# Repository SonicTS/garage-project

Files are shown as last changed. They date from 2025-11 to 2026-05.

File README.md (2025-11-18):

# blaulicht-garage-proxy (MQTT)

A DIY setup that routes the HTTPS traffic of one Android app ("Blaulicht") through a self-hosted mitmproxy. When a specific flow pattern is detected, the mitmproxy addon publishes an MQTT command to a local Mosquitto broker (TLS + auth). An ESP8266 subscribed to that topic pulses a relay to open the garage.

This repo includes: Android per-app VPN client, a mitmproxy addon with MQTT publishing, ESP8266 RTOS-based firmware with MQTT over TLS, and infrastructure templates (systemd, firewall, MQTT broker hardening). Intended for experimentation and learning.

## Data flow (MQTT)

```
[Blaulicht app]
      |
      v
Android per-app VPN (VpnService + tun2socks) → SOCKS5 → mitmproxy --(MQTT/TLS publish)--> Mosquitto → ESP8266 → relay
      ^                                 TLS intercept (trusted CA)                 ^ TLS + auth            (garage door)
```

## Components

- Android per-app VPN client
  - VpnService-based app that forwards only the target app’s traffic via a SOCKS5 proxy (mitmproxy) using a tun2socks AAR.
- mitmproxy addon
  - Detects the flow trigger and publishes `open` to `garage/cmd` over TLS to Mosquitto on 8883.
  - Configurable via environment variables (`MQTT_HOST`, `MQTT_USER/PASS`, `TRIGGER_*`). See `infra/systemd/mitmproxy.service`.
- Mosquitto broker
  - TLS 1.2+, per-user passwords in `/etc/mosquitto/passwd`, and minimal permissions. See `docs/setup-mqtt-broker.md`.
- ESP8266 firmware
  - Connects to Wi‑Fi and MQTT over TLS, subscribes to `garage/cmd`, and publishes `garage/status`. Embed the CA in `lib/mqtt/src/mqtt.c`.

## Quickstart

1) Server (Ubuntu)
- Install Mosquitto and set up TLS + users: `docs/setup-mqtt-broker.md`.
- Deploy mitmproxy addon and set MQTT env: `docs/setup-server-ubuntu.md`.

2) Android
- Build and install the per-app VPN client (Android Studio). Point it to the server’s SOCKS5 port. Install the mitmproxy CA on the device.

3) ESP8266
- Open `esp8266/Garage-Controller` in PlatformIO. Set Wi‑Fi + MQTT config (including CA). Build and flash.

Security note: Use strong per-client credentials. Keep the broker LAN-only or restricted. Self-signed CA is fine for local deployments; keep the private key secure.

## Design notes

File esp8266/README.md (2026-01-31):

# Garage Controller (ESP8266 RTOS)

Wi-Fi–enabled garage controller running on an ESP8266 (ESP-12F) using the
ESP8266 RTOS SDK and PlatformIO.

Main features (planned / in progress):

- STA + AP fallback Wi-Fi manager
- HTTP service interface for configuration
- Persistent configuration storage (Wi-Fi, MQTT, logic)
- Garage control logic (relays, sensors, alarms)
- MQTT integration for remote control / monitoring

## Project layout

- `src/`
  - `main.c` – SDK entrypoint (`user_init` + RF cal) that just calls `app_start()`.
- `lib/`
  - `app/` – top-level orchestration: starts Wi-Fi, HTTP, garage logic, etc.
  - `wifi_manager/` – STA/AP state machine, retries, IP tracking.
  - `service_interface/` – HTTP/REST-style configuration API.
  - `config_store/` – configuration structs + persistence (flash).
  - `garage_control/` – garage-door specific logic (GPIO, sensors, alarms).
  - `mqtt/` – MQTT client wrapper and integration.

## Build / flash

```bash
# Build
pio run

# Upload firmware
pio run -t upload

# Serial monitor
pio device monitor
```

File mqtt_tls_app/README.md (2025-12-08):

# mqtt_tls_app

A new Flutter project.

## Getting Started

This project is a starting point for a Flutter application.

A few resources to get you started if this is your first Flutter project:

- [Lab: Write your first Flutter app](https://docs.flutter.dev/get-started/codelab)
- [Cookbook: Useful Flutter samples](https://docs.flutter.dev/cookbook)

For help getting started with Flutter development, view the
[online documentation](https://docs.flutter.dev/), which offers tutorials,
samples, guidance on mobile development, and a full API reference.

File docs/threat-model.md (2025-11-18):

# Threat Model (MQTT)

Plain-language overview of what we’re defending against and what is out of scope for this hobby setup.

## Goals / What We Try To Protect Against

- Random Internet scanners or bots hitting open ports.
- Opportunistic attackers targeting open MQTT (8883) or SOCKS5 ports.
- Accidental or unauthorized triggering of the garage door via MQTT command injection.
- Simple replay scenarios via repeated publishes if cooldowns are bypassed.

## Non-Goals / Out of Scope

- Highly resourced or motivated attackers targeting the system directly.
- Physical compromise of the ESP8266, relay, or wiring (someone steals the board).
- Advanced MITM attacks against TLS (assumes correct certificate management and no device tampering).
- Protecting against someone who already has root on the server.

## Assets

- Ability to open the garage door.
- MQTT credentials stored in `/etc/mosquitto/passwd`.
- Integrity of command flow between mitmproxy addon and mosquitto broker.

## Attack Surfaces

- MQTT over TLS on 8883 (should be LAN-only or source-restricted).
- SOCKS5 port for the phone (restricted firewall rules recommended).

## Mitigations

- MQTT broker is LAN-only or source-restricted; TLS 1.2+ with strong per-client passwords.
- Separate Unix users `mitmproxy` and `mosq` to reduce lateral impact.
- Firewall: restrict SOCKS5 and 8883; allow SSH.
- TLS on MQTT; self-signed CA with ESP8266 embedding; server key permissions locked down.
- mitmproxy cooldown on publishes to reduce accidental repeats.

## Residual Risks / Trade-offs

- Passwords in mosquitto passwd; protect file mode; consider per-device accounts.
- ESP8266 TLS validation relies on embedded CA; keep CA private key offline.
- No rate limiting on MQTT by default—consider connection limits and auth lockouts.

## Future Hardening Ideas

- Consider mTLS or per-device topics.
- Implement limited command history or deduplication on firmware side.
- Add systemd sandboxing directives for mitmproxy and mosquitto.
- Monitor logs for unusual connection attempts or repeated publishes.

## Summary

Security posture: “Reasonable for a hobby project.” It reduces exposure, uses TLS and per-client credentials, and isolates components. It is not designed for high-assurance environments—treat it as a learning platform.

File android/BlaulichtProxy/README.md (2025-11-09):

# BlaulichtProxy (Android)

This folder holds the Android Studio project for the per-app VPN client.

- VpnService-based app that uses a tun2socks AAR to forward only the Blaulicht app’s traffic to a SOCKS5 proxy (mitmproxy).

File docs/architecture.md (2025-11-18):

# Architecture (MQTT)

This document describes the updated MQTT-based design. mitmproxy detects the app’s flow pattern and publishes an MQTT command to a local Mosquitto broker (TLS + auth). The ESP8266 subscribes to that command topic and publishes status back.

## High-Level Diagram

```
(Android Phone)
+-------------------+      SOCKS5        +------------+       MQTT (TLS)       +--------------------+      Relay
| Blaulicht App     | ---> per-app VPN --|  mitmproxy |--pub--> garage/cmd ---> |   Mosquitto Broker | --->  ESP8266
+-------------------+      (tun2socks)   +------------+<-sub-- garage/status <--+ (localhost:8883)   |   (subscribe cmd,
   | HTTPS Req.             | TLS intercept (CA trusted)                        ^ auth+TLS          |    publish status)
   v                        | inspects flows                                    |                   v
 Normal app logic               | addon publishes command                           |               Garage Door
```

## Step-by-Step Data Flow

1. The Blaulicht app sends HTTPS requests as part of its normal operation.
2. The Android per-app VPN (VpnService + tun2socks) forwards ONLY that app’s TCP streams to mitmproxy (SOCKS5).
3. mitmproxy (trusted CA on the phone) sees HTTP metadata and matches a configured trigger.
4. The mitmproxy addon publishes `GARAGE_CMD_PAYLOAD` (default `open`) to topic `garage/cmd` over TLS to the local Mosquitto broker on 8883.
5. The ESP8266 (RTOS SDK + mbedTLS) is connected to the same broker, subscribes to `garage/cmd`, and when it receives `open`, pulses the relay.
6. The ESP8266 publishes `garage/status` updates (e.g., `idle`, `opening`, `opened`, `closed`) that mitmproxy or dashboards can consume.

## Responsibilities

- mitmproxy: Detects pattern and publishes MQTT command. No long-term state.
- Mosquitto: Authenticates clients, terminates TLS, routes topics.
- ESP8266: MQTT client; subscribes to command topic and publishes status.

## Trust Boundaries

- Broker listens on `localhost:8883` or LAN-restricted 8883/TCP with TLS 1.2+.
- Strong username/password per client; broker runs as locked-down system user.
- Self-signed private CA recommended for local deployments; embed CA in firmware.

## Open Items / TODOs

- Fine-tune mitmproxy trigger conditions (SNI, CONNECT host:port, URL substring).
- Debounce commands (mitmproxy has cooldown; firmware may also enforce cooldown).
- Optional: mTLS or per-device topics like `garage/door1/cmd`.

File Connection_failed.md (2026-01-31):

Flash map=4, rf_cal_sector=1019
Reset reason: 6, exccause=0, epc1=0x00000000
app: Starting app...
app: event queue created
config_store: using flash sector 1018 for config
config_store: loaded config from flash
app: config store initialized
app: config loaded
sleep disable
app: wifi manager initialized
service_interface: starting socket HTTP server on 80 (heap=37280)
service_interface: listening socket=0
app: service interface initialized
app: mqtt client initialized
GPIO init result: 0
garage_control: initialized (task=3fff9760)
app: garage control initialized
mode : sta(c8:c9:a3:38:5b:d3)
add if0
wifi_manager: starting scan for SSID "Barrique"
mqtt: waiting for WIFI_UP...
service_interface: http server task running
scandone
wifi_manager: === Scan Results - All WiFi Networks ===
  SSID: Thomas_Hotspot                   | BSSID: 4a:19:95:d2:f3:e6 | Ch:  6 | RSSI: -34 dBm | Auth: 3
  SSID: Barrique                         | BSSID: 1c:ed:6f:f5:57:1c | Ch: 11 | RSSI: -59 dBm | Auth: 4
wifi_manager: === End of Scan Results ===
wifi_manager: scan done, 1 candidate(s) for SSID "Barrique"
  cand 1: BSSID 1c:ed:6f:f5:57:1c ch=11 rssi=-59
wifi_manager: using BSSID 1c:ed:6f:f5:57:1c, channel 11
wifi_manager: STA connecting to "Barrique"
scandone
state: 0 -> 2 (b0)
state: 2 -> 3 (0)
state: 3 -> 5 (10)
add 0
aid 5
pm open phy_2,type:0 0 0
cnt 
state: 5 -> 2 (2a0)
rm 0
pm close 7 0 0/4042667
wifi_manager: starting scan for SSID "Barrique"
scandone
wifi_manager: === Scan Results - All WiFi Networks ===
  SSID: Barrique_VAP                     | BSSID: 80:3f:5d:83:fd:1e | Ch: 11 | RSSI: -85 dBm | Auth: 3
  SSID: Barrique                         | BSSID: 1c:ed:6f:f5:57:1c | Ch: 11 | RSSI: -59 dBm | Auth: 4
  SSID: Thomas_Hotspot                   | BSSID: 4a:19:95:d2:f3:e6 | Ch:  6 | RSSI: -37 dBm | Auth: 3
wifi_manager: === End of Scan Results ===
wifi_manager: scan done, 1 candidate(s) for SSID "Barrique"
  cand 1: BSSID 1c:ed:6f:f5:57:1c ch=11 rssi=-59
wifi_manager: DHCP timeout, switching candidate
state: 2 -> 0 (0)
wifi_manager: candidates exhausted, trying SSID-only connect (dhcp-timeout
wifi_manager: no BSSID lock, connecting by SSID only
wifi_manager: STA connecting to "Barrique"
wifi_manager: starting scan for SSID "Barrique"
scandone
scandone
wifi_manager: === Scan Results - All WiFi Networks ===
  SSID: Thomas_Hotspot                   | BSSID: 4a:19:95:d2:f3:e6 | Ch:  6 | RSSI: -45 dBm | Auth: 3
  SSID: Barrique                         | BSSID: 1c:ed:6f:f5:57:1c | Ch: 11 | RSSI: -59 dBm | Auth: 4
  SSID: Barrique_VAP                     | BSSID: 80:3f:5d:83:fd:1e | Ch: 11 | RSSI: -91 dBm | Auth: 3
wifi_manager: === End of Scan Results ===
wifi_manager: scan done, 1 candidate(s) for SSID "Barrique"
  cand 1: BSSID 1c:ed:6f:f5:57:1c ch=11 rssi=-59
reconnect
scandone
state: 0 -> 2 (b0)
state: 2 -> 3 (0)
state: 3 -> 5 (10)
add 0
aid 5
pm open phy_2,type:0 0 0
cnt 
state: 5 -> 2 (2a0)
rm 0
pm close 7 0 0/4044221
wifi_manager: starting scan for SSID "Barrique"
scandone
wifi_manager: === Scan Results - All WiFi Networks ===
  SSID: Barrique                         | BSSID: 1c:ed:6f:f5:57:1c | Ch: 11 | RSSI: -59 dBm | Auth: 4
wifi_manager: === End of Scan Results ===
wifi_manager: scan done, 1 candidate(s) for SSID "Barrique"
  cand 1: BSSID 1c:ed:6f:f5:57:1c ch=11 rssi=-59
wifi_manager: DHCP timeout, switching candidate
state: 2 -> 0 (0)
wifi_manager: candidates exhausted, trying SSID-only connect (dhcp-timeout
wifi_manager: no BSSID lock, connecting by SSID only
wifi_manager: STA connecting to "Barrique"
wifi_manager: starting scan for SSID "Barrique"
scandone
scandone
wifi_manager: === Scan Results - All WiFi Networks ===
  SSID: Barrique                         | BSSID: 1c:ed:6f:f5:57:1c | Ch: 11 | RSSI: -57 dBm | Auth: 4
  SSID: Thomas_Hotspot                   | BSSID: 4a:19:95:d2:f3:e6 | Ch:  6 | RSSI: -36 dBm | Auth: 3
wifi_manager: === End of Scan Results ===
wifi_manager: scan done, 1 candidate(s) for SSID "Barrique"
  cand 1: BSSID 1c:ed:6f:f5:57:1c ch=11 rssi=-57
reconnect
scandone
state: 0 -> 2 (b0)
state: 2 -> 3 (0)
state: 3 -> 5 (10)
add 0
aid 5
pm open phy_2,type:0 0 0
cnt 
state: 5 -> 2 (2a0)
rm 0
pm close 7 0 0/4043693
wifi_manager: starting scan for SSID "Barrique"
scandone
wifi_manager: === Scan Results - All WiFi Networks ===
  SSID: Barrique_VAP                     | BSSID: 80:3f:5d:83:fd:1e | Ch: 11 | RSSI: -83 dBm | Auth: 3
  SSID: Thomas_Hotspot                   | BSSID: 4a:19:95:d2:f3:e6 | Ch:  6 | RSSI: -37 dBm | Auth: 3
wifi_manager: === End of Scan Results ===
wifi_manager: scan done, SSID "Barrique" not found -> AP fallback
wifi_manager: switching to AP mode
state: 2 -> 0 (0)
del if0
usl
sul 0 0
mode : softAP(ca:c9:a3:38:5b:d3)
dhcp server start:(ip:192.168.4.1,mask:255.255.255.0,gw:192.168.4.1)
add if1
bcn 100
bcn 0
del if1
usl
sul 0 0
dhcp server start:(ip:192.168.4.1,mask:255.255.255.0,gw:192.168.4.1)
add if1
bcn 100
wifi_manager: SoftAP active: SSID=ESP8266-Setup, password=esp8266pw

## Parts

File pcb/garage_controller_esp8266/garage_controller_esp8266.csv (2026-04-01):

Id | Designator | Footprint | Quantity | Designation | Supplier and ref
1 | R4 | R_0805_2012Metric_Pad1.20x1.40mm_HandSolder | 1 | 0
2 | U1 | Wemos D1 mini connectort | 1 | Wemos D1 mini connector
3 | D1 | LED_0805_2012Metric_Pad1.15x1.40mm_HandSolder | 1 | LED
4 | C1 | C_0805_2012Metric_Pad1.18x1.45mm_HandSolder | 1 | 10uF
5 | Q1,Q3,Q2 | SOT-23 | 3 | 2N7002
6 | R1,R3,R2 | R_0805_2012Metric_Pad1.20x1.40mm_HandSolder | 3 | 1k
7 | C7,C4,C2,C6,C5 | C_0805_2012Metric_Pad1.18x1.45mm_HandSolder | 5 | 100nF
8 | R19,R17,R20,R11,R15,R14 | R_0805_2012Metric_Pad1.20x1.40mm_HandSolder | 6 | 330R
9 | R6,R10,R12,R8,R9,R7 | R_0805_2012Metric_Pad1.20x1.40mm_HandSolder | 6 | 10k
10 | D2 | D_SOD-123 | 1 | 1N5819
11 | R13,R16,R18 | R_0805_2012Metric_Pad1.20x1.40mm_HandSolder | 3 | 100k
12 | U2 | SOIC-28W_7.5x17.9mm_P1.27mm | 1 | MCP23017_SO
13 | J2 | PinSocket_1x03_P2.54mm_Vertical | 1 | Conn_01x03_Socket
14 | R5 | R_1206_3216Metric_Pad1.30x1.75mm_HandSolder | 1 | 3k3
15 | D3,D4 | SOT-323_SC-70 | 2 | SP0502BAJT
16 | J1 | PinSocket_1x09_P2.54mm_Vertical | 1 | Connections
17 | C3 | CP_Elec_10x12.5 | 1 | 220uF

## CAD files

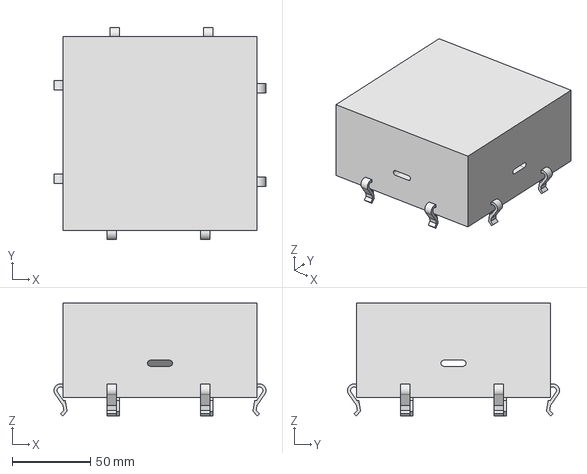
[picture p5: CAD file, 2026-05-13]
pcb/Garage-Box-Project/Top_part_improved.stp
135.7 x 135.7 x 72.2 mm

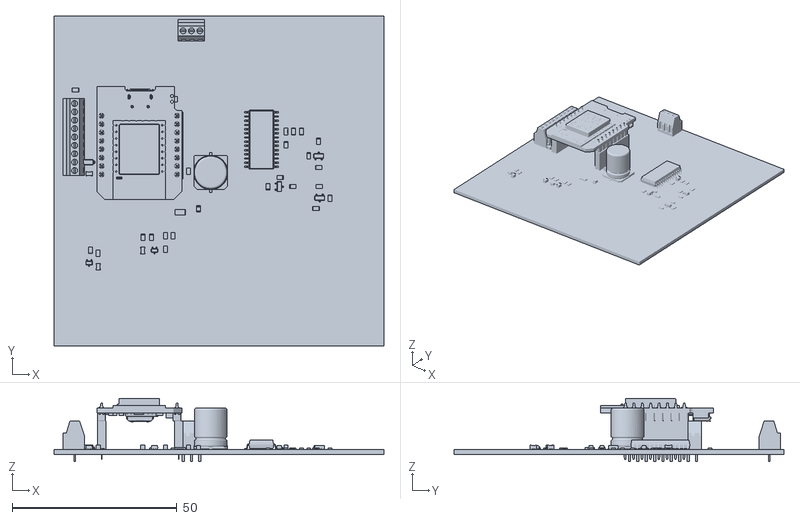
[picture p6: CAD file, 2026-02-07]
pcb/garage_controller_esp8266/Platine.stl
100.0 x 100.0 x 19.2

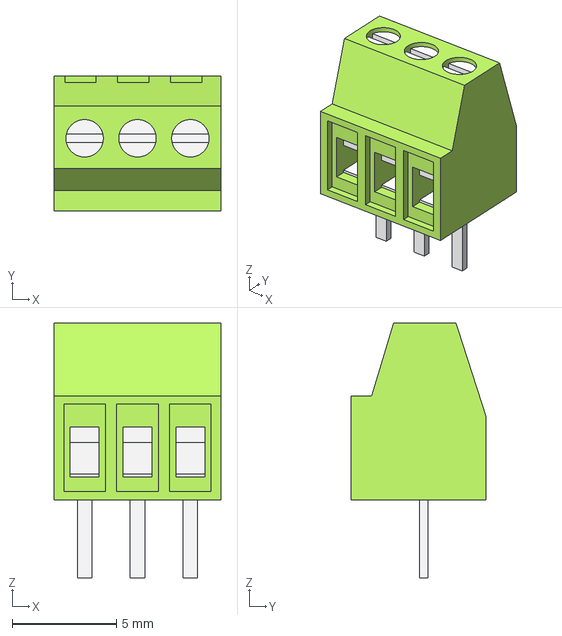
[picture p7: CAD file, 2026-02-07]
pcb/KF128-2.54-3P.step
8.02 x 6.50 x 12.3 mm
Housing
PlasticBody

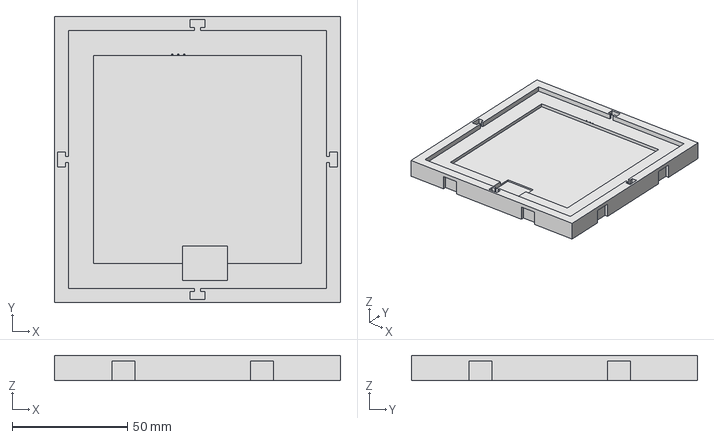
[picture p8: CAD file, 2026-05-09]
pcb/Garage-Box-Project/Bottom_part_improved.stp
124.0 x 124.0 x 11.0 mm

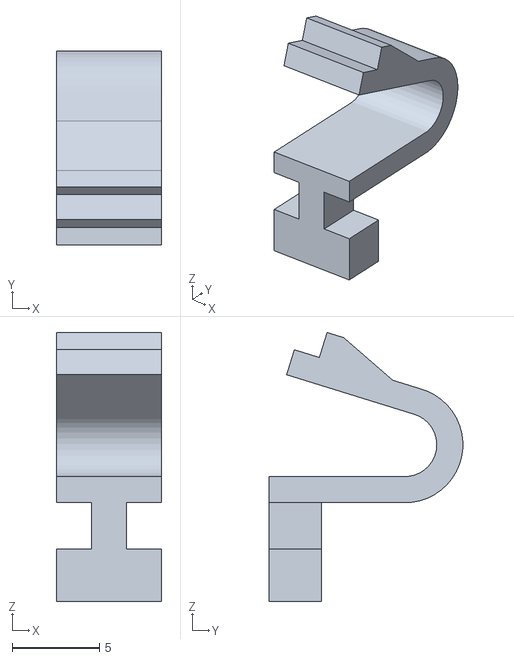
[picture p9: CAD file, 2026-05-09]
pcb/Garage-Box-Project/Clipper_different.stl
6.00 x 11.1 x 15.4

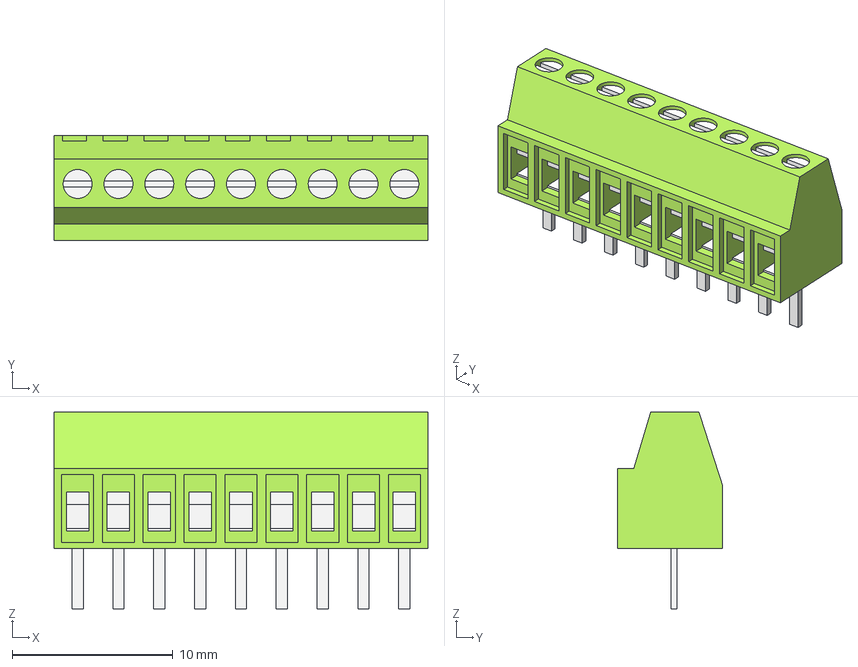
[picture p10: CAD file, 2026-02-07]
pcb/KF128-2.54-9P.step
23.3 x 6.50 x 12.3 mm
Housing
PlasticBody

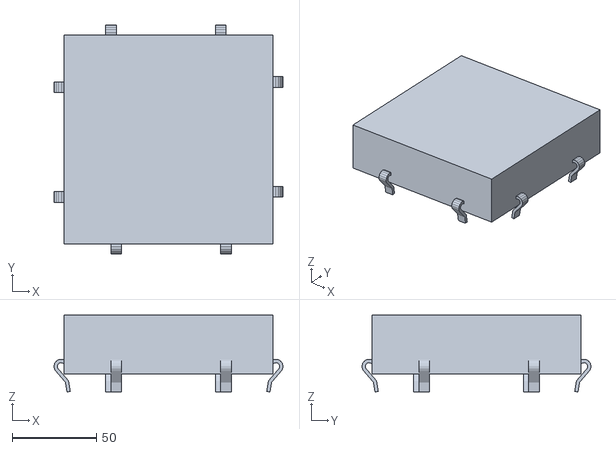
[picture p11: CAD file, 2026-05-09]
pcb/Garage-Box-Project/Top_part_clip.stl
135.7 x 135.7 x 45.6

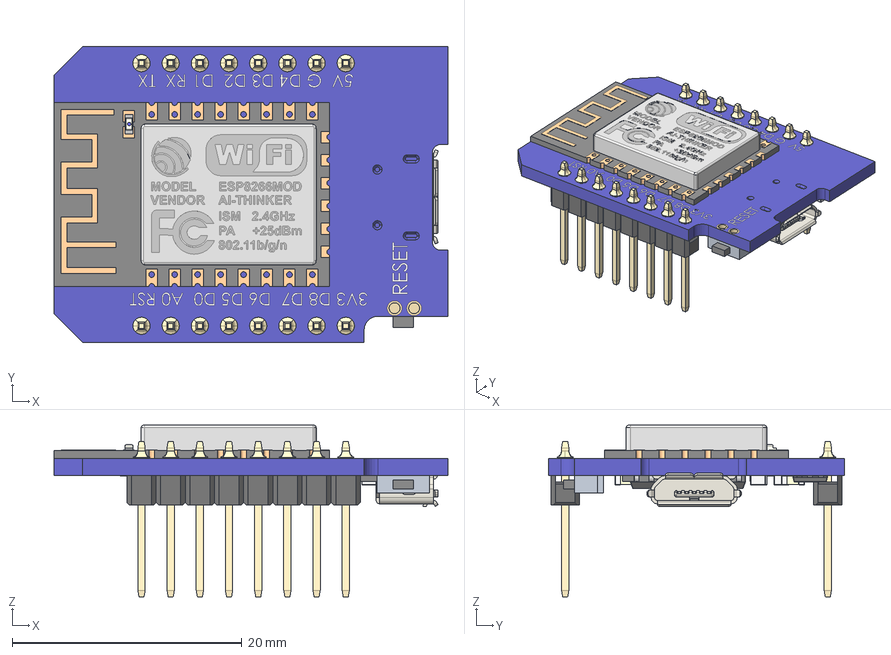
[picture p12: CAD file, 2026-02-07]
pcb/wemos-mini-d1.stp
34.3 x 25.8 x 14.9 mm
PRODUCT_146_ASM_2
PRODUCT_260_3
PRODUCT_323_ASM_2
RES_0805_1 x 12
CAP_0805_1 x 7
SOT23_1_1 x 2
SOT23_2_1 x 2
SOT23_3_1 x 2
SOT23_001_1 x 2
SOT23-5_1
SOT23-5_001_1_1
SOT23-5_001_2_1
SOT23-5_001_3_1
SOT23-5_001_4_1
SOT23-5_001_5_1
SOD-323_1
SOIC-16_150MIL_1
SOIC-16_150MIL_001_1_1
SOIC-16_150MIL_001_2_1
SOIC-16_150MIL_001_3_1
SOIC-16_150MIL_001_4_1
SOIC-16_150MIL_001_5_1
SOIC-16_150MIL_001_6_1
SOIC-16_150MIL_001_7_1
SOIC-16_150MIL_001_8_1
SOIC-16_150MIL_001_9_1
SOIC-16_150MIL_001_10_1
SOIC-16_150MIL_001_11_1
SOIC-16_150MIL_001_12_1
SOIC-16_150MIL_001_13_1
SOIC-16_150MIL_001_14_1
SOIC-16_150MIL_001_15_1
SOIC-16_150MIL_001_16_1
COMPONENTS_2_11__2
_PUSH_BUTTON_-_IMPORTIERT1__2
_USB_SOCKET_-_IMPORTIERT1__2
PCB_2
PIN x 16

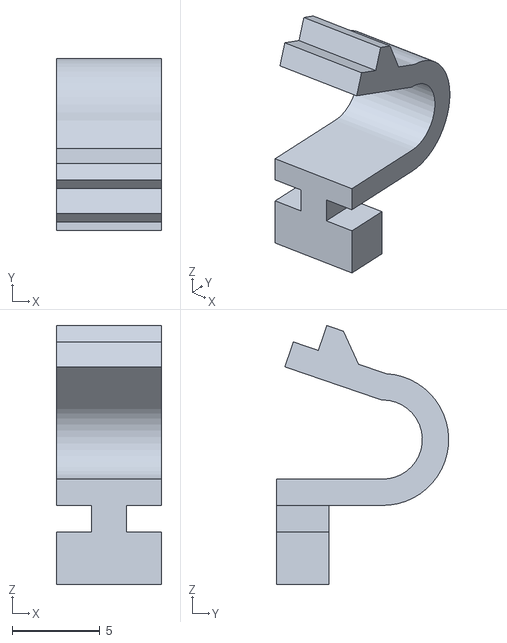
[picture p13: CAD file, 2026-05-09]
pcb/Garage-Box-Project/Clipper_1_5_thickness.stl
6.00 x 9.81 x 14.7

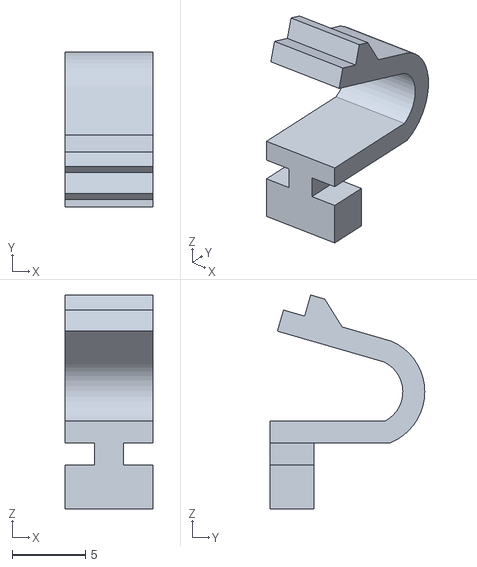
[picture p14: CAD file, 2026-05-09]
pcb/Garage-Box-Project/Clipper_1_5_thickness_smaller.stl
6.00 x 10.6 x 14.6

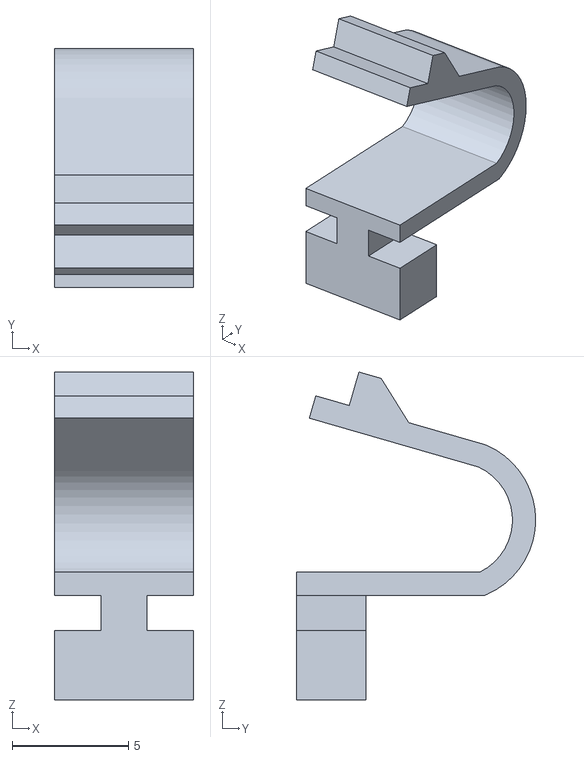
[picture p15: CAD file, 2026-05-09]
pcb/Garage-Box-Project/Clipper_1_0_thickness_smaller.stl
6.00 x 10.3 x 14.1

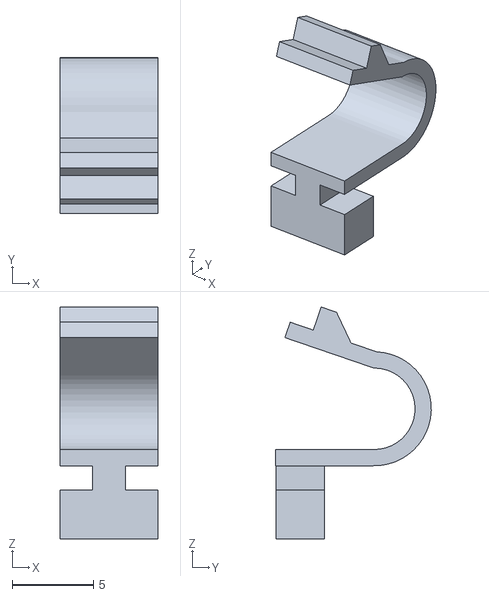
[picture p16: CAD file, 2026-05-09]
pcb/Garage-Box-Project/Clipper_1_0_thickness.stl
6.00 x 9.56 x 14.3

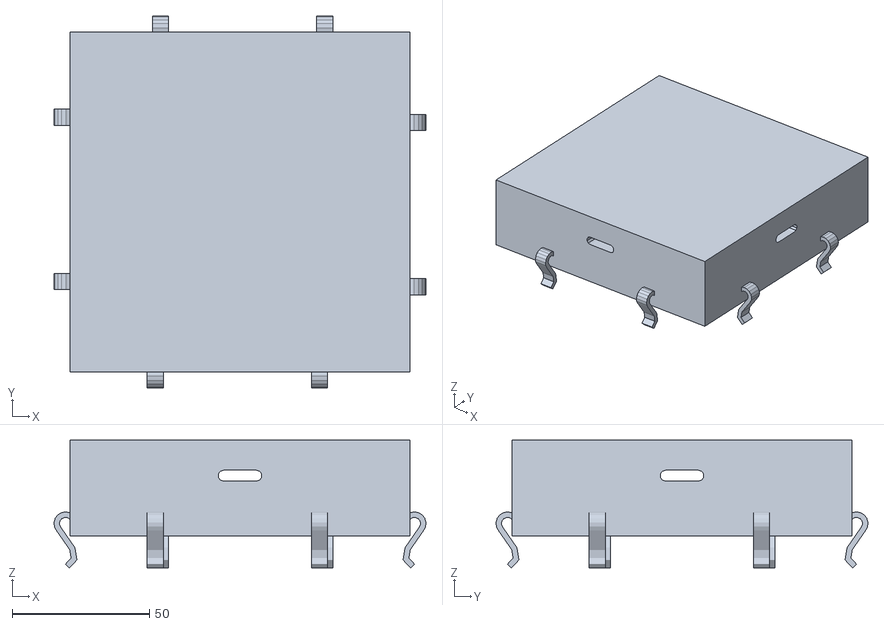
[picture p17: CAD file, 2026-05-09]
pcb/Garage-Box-Project/Top_part.stl
135.7 x 135.7 x 46.7

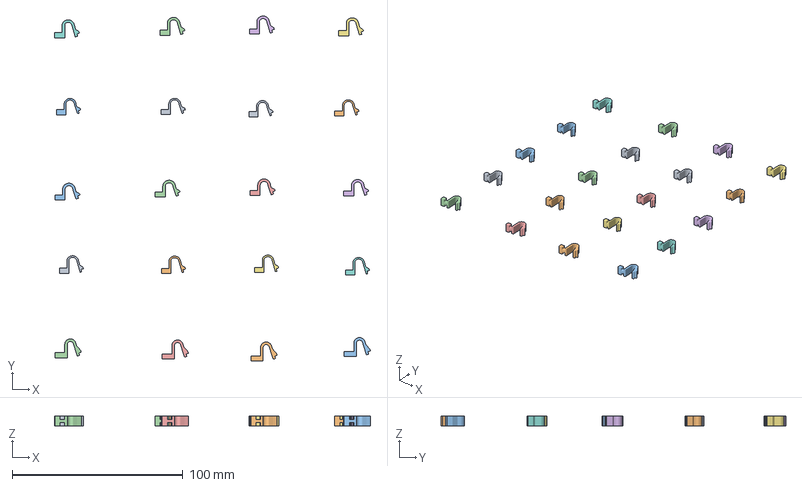
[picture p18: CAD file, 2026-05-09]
pcb/Garage-Box-Project/Clippers.3mf
185.0 x 201.9 x 6.00 mm
Clipper_1_0_thickness.stl x 4
Clipper_1_0_thickness_smaller.stl x 4
Clipper_1_5_thickness.stl x 4
Clipper_1_5_thickness_smaller.stl x 4
Clipper_different.stl x 4

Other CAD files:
pcb/garage_controller_esp8266.step
pcb/Garage-Box-Project/Clipper.stl
pcb/Garage-Box-Project/Clipper_thinner.stl
pcb/Garage-Box-Project/Clipper_wider.stl
pcb/Garage-Box-Project/Assembly_GaragenBox.iam
pcb/Garage-Box-Project/BoxPrintTryout.stl
pcb/Garage-Box-Project/Box_derived.ipt
pcb/Garage-Box-Project/Box_derived.stl
pcb/Garage-Box-Project/Box_with_PCBRefernce.ipt
pcb/Garage-Box-Project/Clipper.ipt
pcb/Garage-Box-Project/Clipper_aligned.ipt
pcb/Garage-Box-Project/OldVersions/Assembly_GaragenBox.0009.iam
pcb/Garage-Box-Project/OldVersions/Box_derived.0006.ipt
pcb/Garage-Box-Project/OldVersions/Box_with_PCBRefernce.0018.ipt
pcb/Garage-Box-Project/OldVersions/Clipper.0017.ipt
pcb/Garage-Box-Project/OldVersions/SolidBody_PCB_better.0003.ipt
pcb/Garage-Box-Project/OldVersions/Top_part.0015.ipt
pcb/Garage-Box-Project/OldVersions/Top_part_only.0001.ipt
pcb/Garage-Box-Project/Part1.stp
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

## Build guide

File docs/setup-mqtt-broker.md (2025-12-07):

# Secure MQTT Broker Setup on Ubuntu (Mosquitto + TLS + Auth)

This guide installs a secure Mosquitto broker with TLS, strong authentication, a dedicated system user, strict permissions, and firewall rules. It’s compatible with ESP8266 (RTOS SDK + mbedTLS) and standard MQTT clients.

## 1) Install Mosquitto Broker & Clients

```bash
sudo apt update
sudo apt install mosquitto mosquitto-clients
```

Verify the service:

```bash
sudo systemctl status mosquitto
```

## 2) Create a Dedicated Mosquitto User

Run Mosquitto as a locked-down system user (create user + group together):

```bash
sudo adduser --system --no-create-home --disabled-password --group mosq
```

## 3) Create Secure TLS Certificates (Self-signed CA)

Use the provided generator script (creates a private CA and a server cert with proper SANs and permissions). Edit the SAN config first, then run the generator:

```bash
sudo mkdir -p /etc/mosquitto/certs
# Copy the SAN config and edit placeholders (LAN IP, hostnames)
sudo cp ./infra/mosquitto/openssl-san.cnf /etc/mosquitto/certs/openssl-san.cnf
sudo nano /etc/mosquitto/certs/openssl-san.cnf

# Generate CA + server cert using the SAN config
sudo bash ./infra/mosquitto/gen-server-cert.sh --config /etc/mosquitto/certs/openssl-san.cnf
```

CA file for devices: `/etc/mosquitto/certs/ca.crt` (copy its PEM contents into your ESP firmware).

## 4) Create Mosquitto Password File (Client Authentication)

```bash
sudo mosquitto_passwd -c /etc/mosquitto/passwd espclient
# Prompted for password

# (Recommended) create a user for mitmproxy addon too:
sudo mosquitto_passwd /etc/mosquitto/passwd mitmclient

sudo chown mosq:mosq /etc/mosquitto/passwd
sudo chmod 600 /etc/mosquitto/passwd
```

Tip: For quick testing only, `mosquitto_sub` can skip hostname verification with `--insecure`, but the proper fix is issuing the server cert with a SAN that matches the host you connect to (e.g. `localhost` or your DNS name).

## 5) Configure Secure Listener (TLS + Auth)

Use the provided infra files

```bash
# Copy ready-to-use configs
sudo cp ./infra/mosquitto/secure.conf /etc/mosquitto/conf.d/secure.conf
sudo cp ./infra/mosquitto/acl /etc/mosquitto/acl

# Ensure mosquitto runs as custom user mosq with sane pre-start steps
sudo mkdir -p /etc/systemd/system/mosquitto.service.d
sudo cp ./infra/mosquitto/override.conf /etc/systemd/system/mosquitto.service.d/override.conf
sudo systemctl daemon-reload
```

Reload and check logs:

```bash
sudo systemctl restart mosquitto
sudo journalctl -u mosquitto -f
```

If you see errors like:

```
Error: Unable to open log file /var/log/mosquitto/mosquitto.log for writing.
Error: Unable to load server key file "/etc/mosquitto/certs/server.key". Check keyfile.
```

Fix them:

1. Ensure the runtime user matches file ownership. Using custom user `mosq` everywhere is recommended; all certs, key, CA, passwd and log directory must be owned by `mosq:mosq` with restrictive permissions on the private key.
  - To confirm custom user is applied:
    ```bash
    sudo systemctl edit mosquitto
    # In the editor ensure:
    [Service]
    User=mosq
    Group=mosq
    ```
    Then reload:
    ```bash
    sudo systemctl daemon-reload
    ```
  - Or revert the line in `secure.conf` to `user mosquitto` and adjust ownership:
    ```bash
    sudo chown mosquitto:mosquitto /etc/mosquitto/certs/server.key /etc/mosquitto/certs/server.crt /etc/mosquitto/certs/ca.crt
    sudo chown mosquitto:mosquitto /etc/mosquitto/passwd
    ```
2. Create log directory and file with correct ownership (only if using file logging):
  ```bash
  sudo mkdir -p /var/log/mosquitto
  sudo touch /var/log/mosquitto/mosquitto.log
  sudo chown mosq:mosq /var/log/mosquitto/mosquitto.log /var/log/mosquitto
  sudo chmod 640 /var/log/mosquitto/mosquitto.log
  # (Use mosquitto:mosquitto if you reverted user.)
  ```
3. Restart again:
  ```bash
  sudo systemctl restart mosquitto
  sudo journalctl -u mosquitto -f
  ```

Optional: Instead of a file log, you can remove any `log_dest file` directive and rely on syslog (`log_dest syslog`) to avoid managing permissions.

## 6a) Troubleshooting "Protocol error" on TLS connect

If `mosquitto_sub` reports `Error: Protocol error` on a TLS listener:

Likely causes:
- Wrong port (connecting TLS client to a plain listener or vice versa).
- Certificate/key unreadable by runtime user (results in the broker starting without TLS, or failing; verify service status).
- Client missing `--cafile` or using an incorrect CA (handshake aborts early).
- Corrupted or wrong format key/certificate (must be PEM, not DER).
- Mixed permissions (server.key not readable by the broker user).

Diagnostics:
```bash
sudo systemctl status mosquitto
sudo journalctl -u mosquitto | tail -n 30
openssl s_client -connect localhost:8883 -servername localhost -CAfile /etc/mosquitto/certs/ca.crt -quiet
mosquitto_sub -d -h localhost -p 8883 --cafile /etc/mosquitto/certs/ca.crt -u espclient -P 'YOURPASSWORD' -t test/topic
```

Check that `openssl s_client` ends with `Verify return code: 0 (ok)`.

Permissions sanity:
```bash
ls -l /etc/mosquitto/certs
ls -l /etc/mosquitto/passwd
```

Expected:
- `server.key` : `-rw------- mosq mosq`
- `server.crt` / `ca.crt` : `-rw-r--r-- mosq mosq`
- `passwd` : `-rw------- mosq mosq`

If the broker runs as default user instead, adjust ownership to `mosquitto:mosquitto` accordingly.

Regenerate a broken key/cert pair (if needed):
```bash
cd /etc/mosquitto/certs
sudo openssl genrsa -out server.key 2048
sudo openssl req -new -key server.key -out server.csr
sudo openssl x509 -req -in server.csr -CA ca.crt -CAkey ca.key -CAcreateserial -out server.crt -days 3650
sudo rm server.csr
sudo chown mosq:mosq server.key server.crt
sudo chmod 600 server.key
sudo chmod 644 server.crt
sudo systemctl restart mosquitto
```

## 6) Firewall (iptables)

```bash
# Allow TLS MQTT 8883 (any source)
sudo iptables -A INPUT -p tcp --dport 8883 -j ACCEPT

# Optional: restrict to LAN instead of anywhere
# sudo iptables -A INPUT -p tcp -s 192.168.0.0/16 --dport 8883 -j ACCEPT

# Persist rules across reboots (Debian/Ubuntu)
sudo apt install -y iptables-persistent
sudo netfilter-persistent save
```

Allow entire private networks (RFC1918) only:

```bash
# 10.0.0.0/8
sudo iptables -A INPUT -p tcp -s 10.0.0.0/8 --dport 8883 -j ACCEPT
# 172.16.0.0/12
sudo iptables -A INPUT -p tcp -s 172.16.0.0/12 --dport 8883 -j ACCEPT
# 192.168.0.0/16
sudo iptables -A INPUT -p tcp -s 192.168.0.0/16 --dport 8883 -j ACCEPT

# Remove any broad allow added earlier if present
# sudo iptables -D INPUT -p tcp --dport 8883 -j ACCEPT || true

sudo netfilter-persistent save
```

Tip (TLS SAN when you don’t have a domain or stable public IP):
- Include entries you actually use: `DNS:localhost`, `IP:127.0.0.1`, your LAN IP `IP:<LAN_IP>`.
- For outside access without a domain, either use a free DDNS (DuckDNS, No-IP, Dynu) and put `DNS:<your-ddns>` in SAN, or connect by your current public IP and include that `IP:<PUBLIC_IP>` in SAN (you’ll need to reissue the cert when it changes). For quick tests, clients like mosquitto_sub can use `--insecure` to skip hostname verification.

## 7) Test the Broker

Terminal A (subscribe):

```bash
mosquitto_sub -v \
  -h localhost \
  -p 8883 \
  --cafile /etc/mosquitto/certs/ca.crt \
  -u espclient \
  -P "12_espclient_34" \
  -t "garage/topic"
```

Terminal B (publish):

```bash
mosquitto_pub \
  -h localhost \
  -p 8883 \
  --cafile /etc/mosquitto/certs/ca.crt \
  -u espclient \
  -P "12_espclient_34" \
  -t "garage/cmd" \
  -m "OPEN"
```

Expected output in terminal A:

```
test/topic Hello MQTT!
```

## 11) Final Checklist

- User and ownership:
  - Runtime user `mosq` exists: `id mosq`
  - Certs and passwd owned by `mosq:mosq`: `ls -l /etc/mosquitto/certs /etc/mosquitto/passwd`
  - Permissions: `server.key` 600; `server.crt` and `ca.crt` 644; `passwd` 600
- TLS certificate:
  - SAN includes what you connect to: `localhost`, `<LAN_IP>`, and optionally `<YOUR_DDNS_OR_HOSTNAME>`
  - Verify: `openssl x509 -in /etc/mosquitto/certs/server.crt -noout -text | sed -n '/Subject Alternative Name/,+1p'`
  - Handshake: `openssl s_client -connect localhost:8883 -servername localhost -CAfile /etc/mosquitto/certs/ca.crt -quiet` should end with `Verify return code: 0 (ok)`
- Mosquitto config:
  - `per_listener_settings true` appears before any security lines
  - Listener 8883 has `cafile/certfile/keyfile/tls_version`
  - Security after listener: `user mosq`, `allow_anonymous false`, `password_file ...`, optional `acl_file`
- Auth:
  - Password set: `sudo mosquitto_passwd -b /etc/mosquitto/passwd espclient 'YOURPASSWORD'`
  - Optional ACL grants topics to `espclient`
- Firewall:
  - Open TCP 8883 via iptables (optionally restrict to LAN or RFC1918)

After any change:
```bash
sudo systemctl restart mosquitto
sudo journalctl -u mosquitto -f
```

## 8) ESP8266 Compatibility

Configure firmware with:
- host: broker IP (or hostname)
- port: 8883
- TLS: enabled
- username/password: `espclient` and its password
- CA certificate: paste contents of `/etc/mosquitto/certs/ca.crt` into the firmware’s CA array (PEM)

Topics (suggested):
- Commands: `garage/cmd` (payload: `open`)
- Status: `garage/status` (payloads: `idle`, `opening`, `opened`, `closed`, etc.)

## 9) Optional Hardening

In `/etc/mosquitto/conf.d/secure.conf` you can add:

```
message_size_limit 10240
max_connections 20
```

Disable unencrypted MQTT:

```bash
sudo nano /etc/mosquitto/mosquitto.conf
# add: port 0
sudo systemctl restart mosquitto
```

## 10) Allowing mitmproxy access to manage users (optional)

Clients do not need to read `/etc/mosquitto/passwd`. If you want the `mitmproxy` system user to manage users, prefer `sudoers` for the `mosquitto_passwd` tool:

```bash
sudo visudo -f /etc/sudoers.d/mitmproxy-mosquitto
```

Add:

```
mitmproxy ALL=(root) NOPASSWD: /usr/bin/mosquitto_passwd *
```

If you must grant read access to `/etc/mosquitto/passwd` (not recommended):

```bash
sudo chgrp mitmproxy /etc/mosquitto/passwd
sudo chmod 640 /etc/mosquitto/passwd
```

Security note: prefer not sharing the password file; use per-client credentials and keep file mode `600` owned by `mosq:mosq`.

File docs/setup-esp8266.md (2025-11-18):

# ESP8266 Setup (MQTT)

The firmware (PlatformIO, ESP8266 RTOS SDK) connects to Wi‑Fi and to your Mosquitto broker over TLS, subscribes to `garage/cmd`, and publishes status on `garage/status`. The MQTT client is implemented in `esp8266/Garage-Controller/lib/mqtt` using mbedTLS.

## Configure Wi‑Fi + MQTT

Edit the configuration via `config_store` defaults or your own UI. Key fields (structs in `lib/config_store/include/config_store.h`):

- `wifi.ssid`, `wifi.password`
- `mqtt.broker` (e.g. `192.168.1.10`), `mqtt.port = 8883`
- `mqtt.client_id` (e.g. `garage-esp`)
- `mqtt.username`, `mqtt.password` (created with `mosquitto_passwd`)
- `mqtt.base_topic` (e.g. `garage/door1`) – used by the helper publisher
- `mqtt.use_tls = 1`

Embed your CA certificate (PEM) in `lib/mqtt/src/mqtt.c` by replacing the placeholder inside `mqtt_ca_pem[]` with the content of `/etc/mosquitto/certs/ca.crt`:

```
static const char mqtt_ca_pem[] =
"-----BEGIN CERTIFICATE-----\n"
"... paste ca.crt PEM here ...\n"
"-----END CERTIFICATE-----\n";
```

Topics:
- Commands (subscribe): `garage/cmd` (payload: `open`)
- Status (publish): `garage/status` (payloads like `idle`, `opening`, `opened`, `closed`)

The helper `mqtt_client_publish_status(subtopic, payload)` publishes to `${base_topic}/${subtopic}`; for a flat topic like `garage/status`, set `base_topic="garage"` and subtopic to `status`.

## Build & Flash (PlatformIO)

1) Open `esp8266/Garage-Controller` in VS Code with the PlatformIO extension.
2) Update configuration as above and paste the CA certificate.
3) Build (PlatformIO: Build) and Upload (PlatformIO: Upload) to your board.
4) Monitor serial output to confirm Wi‑Fi + MQTT connection and command handling.

## Notes

- Ensure RTC/peripherals meet your relay board’s logic level and activation polarity.
- Implement relay cooldown in your app logic to avoid rapid toggles.
- For mTLS, you could extend `mqtt.c` to load a client cert/key if desired.

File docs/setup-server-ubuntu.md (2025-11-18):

# Server Setup (Ubuntu) – mitmproxy + Mosquitto (MQTT)

This guide sets up mitmproxy and a secure MQTT broker (Mosquitto with TLS + auth). The ESP8266 will subscribe to commands and publish status via MQTT. No HTTP polling service is required anymore.

## 1. Prerequisites

- Ubuntu 22.04 LTS (or similar) with root/sudo access.
- Stable public DNS name / DDNS for the ESP8266 to reach (`<DOMAIN_OR_DDNS>`).
- Ability to install packages and open firewall ports.

## 2. Create Service Users

Create dedicated unprivileged users to run each component:

```bash
sudo adduser --system --group mitmproxy
sudo adduser --system --group mosq
```

Rationale: Least privilege separation. Each process has its own user.

## 3. Install Dependencies

```bash
sudo apt update
sudo apt install -y python3 python3-venv python3-pip mitmproxy mosquitto mosquitto-clients ufw
```

Optional: `tmux`, `git`, `ufw`, `fail2ban` for operational convenience.

## 4. Install and Secure Mosquitto (TLS + Auth)

Follow the dedicated guide in `docs/setup-mqtt-broker.md` (self-signed CA recommended for local networks). Summary:

- Create `/etc/mosquitto/certs` and generate CA + server certs.
- Create `/etc/mosquitto/passwd` and add users (e.g., `espclient`, `mitmclient`).
- Add `/etc/mosquitto/conf.d/secure.conf` with TLS listener on 8883, `allow_anonymous false`, and `user mosq`.
- `sudo systemctl restart mosquitto` and test with `mosquitto_sub/pub` using `--cafile` and credentials.

## 5. Deploy mitmproxy

Run mitmproxy as the `mitmproxy` user. The addon script should reside under an owned directory:

```bash
sudo mkdir -p /opt/blaulicht/mitmproxy
sudo chown -R mitmproxy:mitmproxy /opt/blaulicht/mitmproxy
# (Old approach) If using a confdir inside /opt: sudo -u mitmproxy mkdir -p /opt/blaulicht/mitmproxy/.mitmproxy
# New recommended approach relies on systemd StateDirectory=mitmproxy which auto-creates /var/lib/mitmproxy
sudo rsync -av ./mitmproxy/ /opt/blaulicht/mitmproxy/
sudo -u mitmproxy python3 -m venv /opt/blaulicht/mitmproxy/venv
sudo -u mitmproxy /opt/blaulicht/mitmproxy/venv/bin/pip install -r /opt/blaulicht/mitmproxy/requirements.txt
```

Test manually (optional) – explicitly set a writable confdir because system users often have HOME=/nonexistent:

```bash
sudo -u mitmproxy mitmdump --set confdir=/var/lib/mitmproxy --mode socks5 --listen-host 0.0.0.0 --listen-port 8281 -s /opt/blaulicht/mitmproxy/garage_trigger.py
```

> TODO: Confirm the Android app’s per-app VPN points to this server’s IP and port 8281.

## 6. systemd Units

Copy unit files:

```bash
sudo cp ./infra/systemd/mitmproxy.service /etc/systemd/system/
## 6.1 MQTT credentials for mitmproxy addon

Create environment file for the addon to reach the broker securely:

```bash
sudo mkdir -p /etc/blaulicht
sudo tee /etc/blaulicht/mqtt.env >/dev/null <<'EOF'
MQTT_HOST=127.0.0.1
MQTT_PORT=8883
MQTT_USER=mitmclient
MQTT_PASS=REPLACE_WITH_STRONG_PASSWORD
MQTT_CAFILE=/etc/mosquitto/certs/ca.crt
GARAGE_CMD_TOPIC=garage/cmd
GARAGE_CMD_PAYLOAD=open
# Example trigger: exact SNI match, or URL contains, or CONNECT host/port
#TRIGGER_SNI=
#TRIGGER_URL_CONTAINS=
#TRIGGER_CONNECT_HOST=
#TRIGGER_CONNECT_PORT=
PUBLISH_COOLDOWN_SEC=10
EOF
```

Set readable permissions for mitmproxy:

```bash
sudo chown root:mitmproxy /etc/blaulicht/mqtt.env
sudo chmod 640 /etc/blaulicht/mqtt.env
```
```

With the updated unit file including `StateDirectory=mitmproxy`, systemd will create `/var/lib/mitmproxy` automatically at start. No manual confdir creation is needed. If you are on the old unit file, create the legacy path manually.

Reload and enable:

```bash
sudo systemctl daemon-reload
sudo systemctl enable --now mitmproxy.service
```

Check status:

```bash
systemctl status mitmproxy.service
```

### Allowing mitmproxy to manage Mosquitto users (optional)

Clients do not need to read `/etc/mosquitto/passwd`; they just authenticate. If you want the `mitmproxy` user to run `mosquitto_passwd` (to add/change users) without full root, prefer `sudoers` for that command:

```bash
sudo visudo -f /etc/sudoers.d/mitmproxy-mosquitto
```

Add:

```
mitmproxy ALL=(root) NOPASSWD: /usr/bin/mosquitto_passwd *
```

If you instead want to grant read access to the password file (not recommended), you can loosen permissions:

```bash
sudo chgrp mitmproxy /etc/mosquitto/passwd
sudo chmod 640 /etc/mosquitto/passwd
```

Security note: the broker still verifies passwords internally; reading the file is sensitive and should be avoided.
```

## 7. Firewall / UFW

## 8. Firewall / UFW

Basic example (adjust to your threat model):

```bash
sudo ufw default deny incoming
sudo ufw default allow outgoing
sudo ufw allow proto tcp from <YOUR_PHONE_IP> to any port 8281   # SOCKS5 (restricted)
sudo ufw allow 8883/tcp                                         # MQTT over TLS
sudo ufw allow ssh                                             # Consider restricting source IPs
sudo ufw enable
```

Refer to `infra/firewall-notes.md` for more narrative guidance.

## 8. mitmproxy CA on Android

Export mitmproxy CA certificate (mitmproxy generates it on first run in `~/.mitmproxy/`). Install it as a user CA on the Android device (Developer options may be required on newer versions).

## 9. Monitoring & Logs (Optional)

- Tail logs (systemd journal):
	- `journalctl -u mitmproxy -f`
- File logs (if using `--set logfile=/var/log/mitmproxy/mitmproxy.log`):
	- `tail -f /var/log/mitmproxy/mitmproxy.log`
- Add log rotation (example `/etc/logrotate.d/mitmproxy`):

```bash
sudo tee /etc/logrotate.d/mitmproxy >/dev/null <<'EOF'
/var/log/mitmproxy/mitmproxy.log {
		daily
		rotate 7
		compress
		missingok
		notifempty
		create 640 mitmproxy mitmproxy
}
EOF
```

- Consider minimal structured logging or filtering sensitive headers before writing to disk.

## 10. TODO / Hardening Ideas

- Consider mTLS on MQTT if device can handle certs.
- Add systemd `ProtectSystem=full` / `NoNewPrivileges=yes` etc. (advanced hardening).
- Consider running mitmproxy with a fixed certificate set if needed.

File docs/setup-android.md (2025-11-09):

# Android Setup (Per-App VPN)

The Android client is a VpnService-based app that forwards only the Blaulicht app’s traffic through a SOCKS5 proxy (mitmproxy) using a tun2socks AAR.

> Note: The tun2socks AAR is assumed to be prebuilt elsewhere and not included here.

## Steps

1. Import the project
   - Open Android Studio.
   - File → Open… → select `android/BlaulichtProxy/` (this folder is a placeholder for your actual project).

2. Add the tun2socks AAR
   - Place your `socks-tun2socks.aar` in the app module’s libs folder, e.g. `android/BlaulichtProxy/app/libs/socks-tun2socks.aar`.
   - In `build.gradle`, add:
     - `repositories { flatDir { dirs 'libs' } }`
     - `implementation(name: 'socks-tun2socks', ext: 'aar')`

3. Configure per-app VPN
   - Use `VpnService` to establish the TUN interface.
   - Configure the per-app restriction so only the Blaulicht package’s UID is routed (App Exclusions/Inclusions depending on API level).
   - Use tun2socks to forward TCP connections to a SOCKS5 endpoint.

4. Proxy settings (UI)
   - Expose a simple settings screen to set:
     - Host: `<DOMAIN_OR_DDNS>` of your server
     - Port: `8281` (or the configured SOCKS5 port)

5. Trust the mitmproxy CA
   - Install the mitmproxy CA certificate on the device so TLS interception works.
   - On modern Android, user-added CAs aren’t trusted by apps by default; you may need to opt-in via Network Security Config for debugging, or use a rooted device/emulator for testing.

6. Build & Install
   - Build the APK and install it on your test device.
   - Start the VPN and verify that only the Blaulicht app’s traffic is routed via mitmproxy.

## Notes / TODOs

- Consider adding a kill-switch for when the proxy is unreachable.
- Ensure the app doesn’t capture system/other apps unless intended.
- Handle IPv6 if your network or app uses it.
- Provide a minimal log view for troubleshooting.

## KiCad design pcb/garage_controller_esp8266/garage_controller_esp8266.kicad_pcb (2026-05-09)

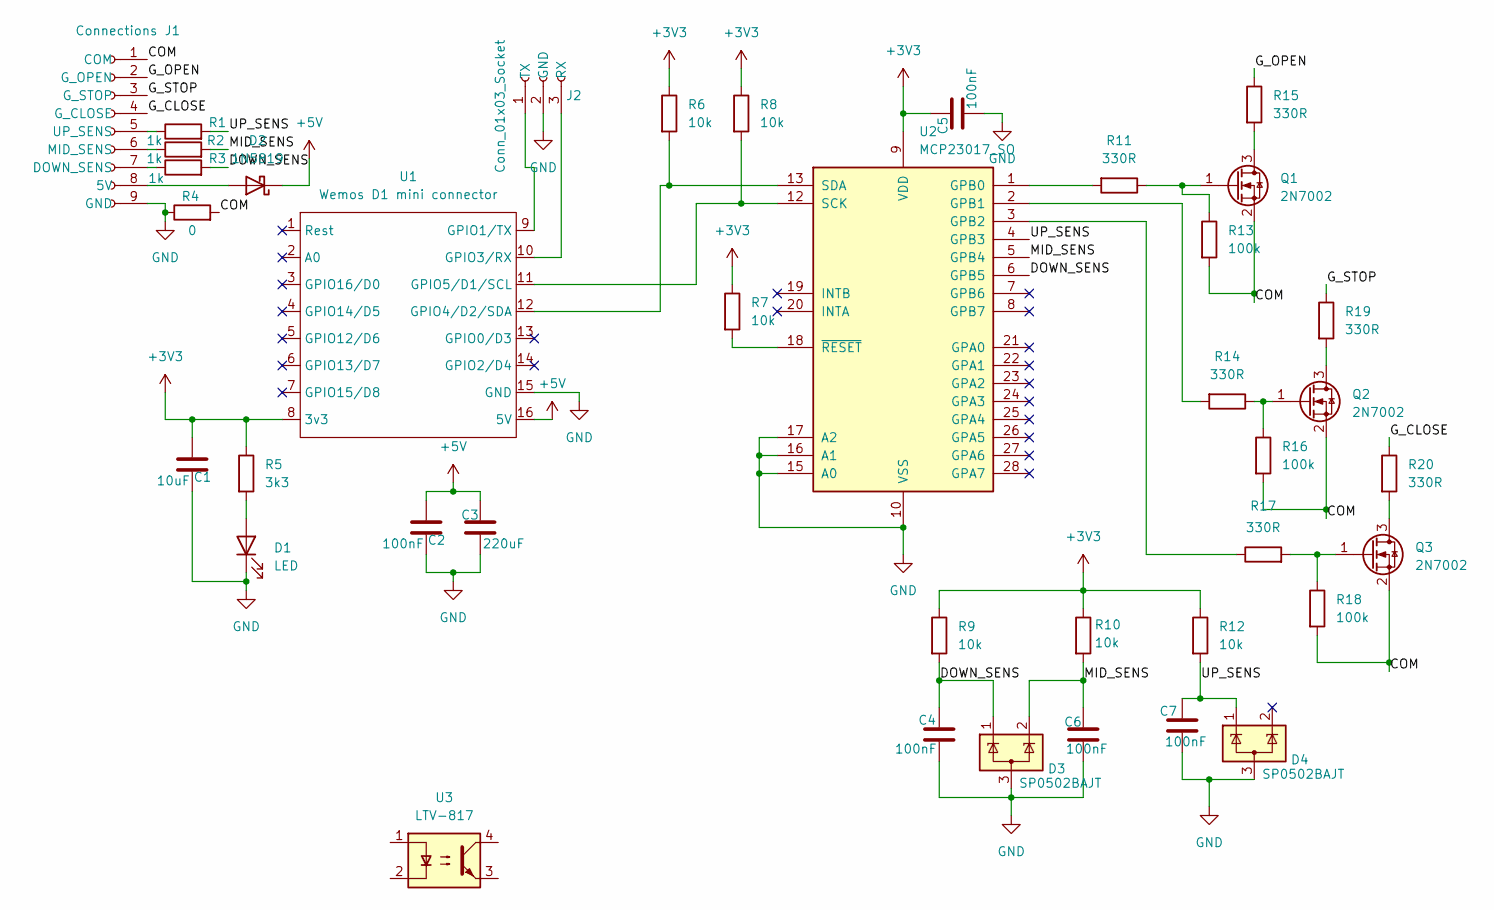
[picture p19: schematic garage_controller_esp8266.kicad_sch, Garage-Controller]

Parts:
C1: 10uF; C_0805_2012Metric_Pad1.18x1.45mm_HandSolder
C2, C4, C5, C6, C7: 100nF; C_0805_2012Metric_Pad1.18x1.45mm_HandSolder
C3: 220uF; CP_Elec_10x12.5
D1: LED; LED_0805_2012Metric_Pad1.15x1.40mm_HandSolder
D2: 1N5819; D_SOD-123
D3, D4: SP0502BAJT; SOT-323_SC-70
J1: Connections; PinSocket_1x09_P2.54mm_Vertical
J2: Conn_01x03_Socket; PinSocket_1x03_P2.54mm_Vertical
Q1, Q2, Q3: 2N7002; SOT-23
R1, R2, R3: 1k; R_0805_2012Metric_Pad1.20x1.40mm_HandSolder
R4: 0; R_0805_2012Metric_Pad1.20x1.40mm_HandSolder
R5: 3k3; R_1206_3216Metric_Pad1.30x1.75mm_HandSolder
R6, R7, R8, R9, R10, R12: 10k; R_0805_2012Metric_Pad1.20x1.40mm_HandSolder
R11, R14, R15, R17, R19, R20: 330R; R_0805_2012Metric_Pad1.20x1.40mm_HandSolder
R13, R16, R18: 100k; R_0805_2012Metric_Pad1.20x1.40mm_HandSolder
U1: Wemos D1 mini connector; Wemos D1 mini connectort
U2: MCP23017_SO; SOIC-28W_7.5x17.9mm_P1.27mm
U3: LTV-817; DIP-4_W7.62mm

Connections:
+3V3: C1.2, C5.1, R5.1, R6.1, R7.1, R8.1, R9.1, R10.1, R12.1, U1.8 (3v3), U2.9 (VDD)
+5V: C2.2, C3.1, D2.1 (K), U1.16 (5V)
/COM: J1.1 (COM), Q1.2 (S), Q2.2 (S), Q3.2 (S), R4.2, R13.2, R16.2, R18.2
/DOWN_SENS: C4.1, D3.1 (K), R3.2, R9.2, U2.6 (GPB5)
/G_CLOSE: J1.4 (G_CLOSE), R20.1
/G_OPEN: J1.2 (G_OPEN), R15.1
/G_STOP: J1.3 (G_STOP), R19.1
/MID_SENS: C6.1, D3.2 (K), R2.2, R10.2, U2.5 (GPB4)
/UP_SENS: C7.1, D4.1 (K), R1.2, R12.2, U2.4 (GPB3)
GND: C1.1, C2.1, C3.2, C4.2, C5.2, C6.2, C7.2, D1.1 (K), D3.3 (A), D4.3 (A), J1.9 (GND), J2.2 (GND), R4.1, U1.15 (GND), U2.10 (VSS), U2.15 (A0), U2.16 (A1), U2.17 (A2)
unnamed: D1.2 (A), R5.2
unnamed: D2.2 (A), J1.8 (5V)
unnamed: J1.7 (DOWN_SENS), R3.1
unnamed: J1.6 (MID_SENS), R2.1
unnamed: J1.5 (UP_SENS), R1.1
unnamed: J2.3 (RX), U1.10 (GPIO3/RX)
unnamed: J2.1 (TX), U1.9 (GPIO1/TX)
unnamed: Q1.3 (D), R15.2
unnamed: Q1.1 (G), R11.1, R13.1
unnamed: Q2.3 (D), R19.2
unnamed: Q2.1 (G), R14.1, R16.1
unnamed: Q3.3 (D), R20.2
unnamed: Q3.1 (G), R17.2, R18.1
unnamed: R6.2, U1.12 (GPIO4/D2/SDA), U2.13 (SDA)
unnamed: R8.2, U1.11 (GPIO5/D1/SCL), U2.12 (SCK)
unnamed: R11.2, U2.1 (GPB0)
unnamed: R14.2, U2.2 (GPB1)
unnamed: R17.1, U2.3 (GPB2)
unnamed: R7.2, U2.18 (~RESET)

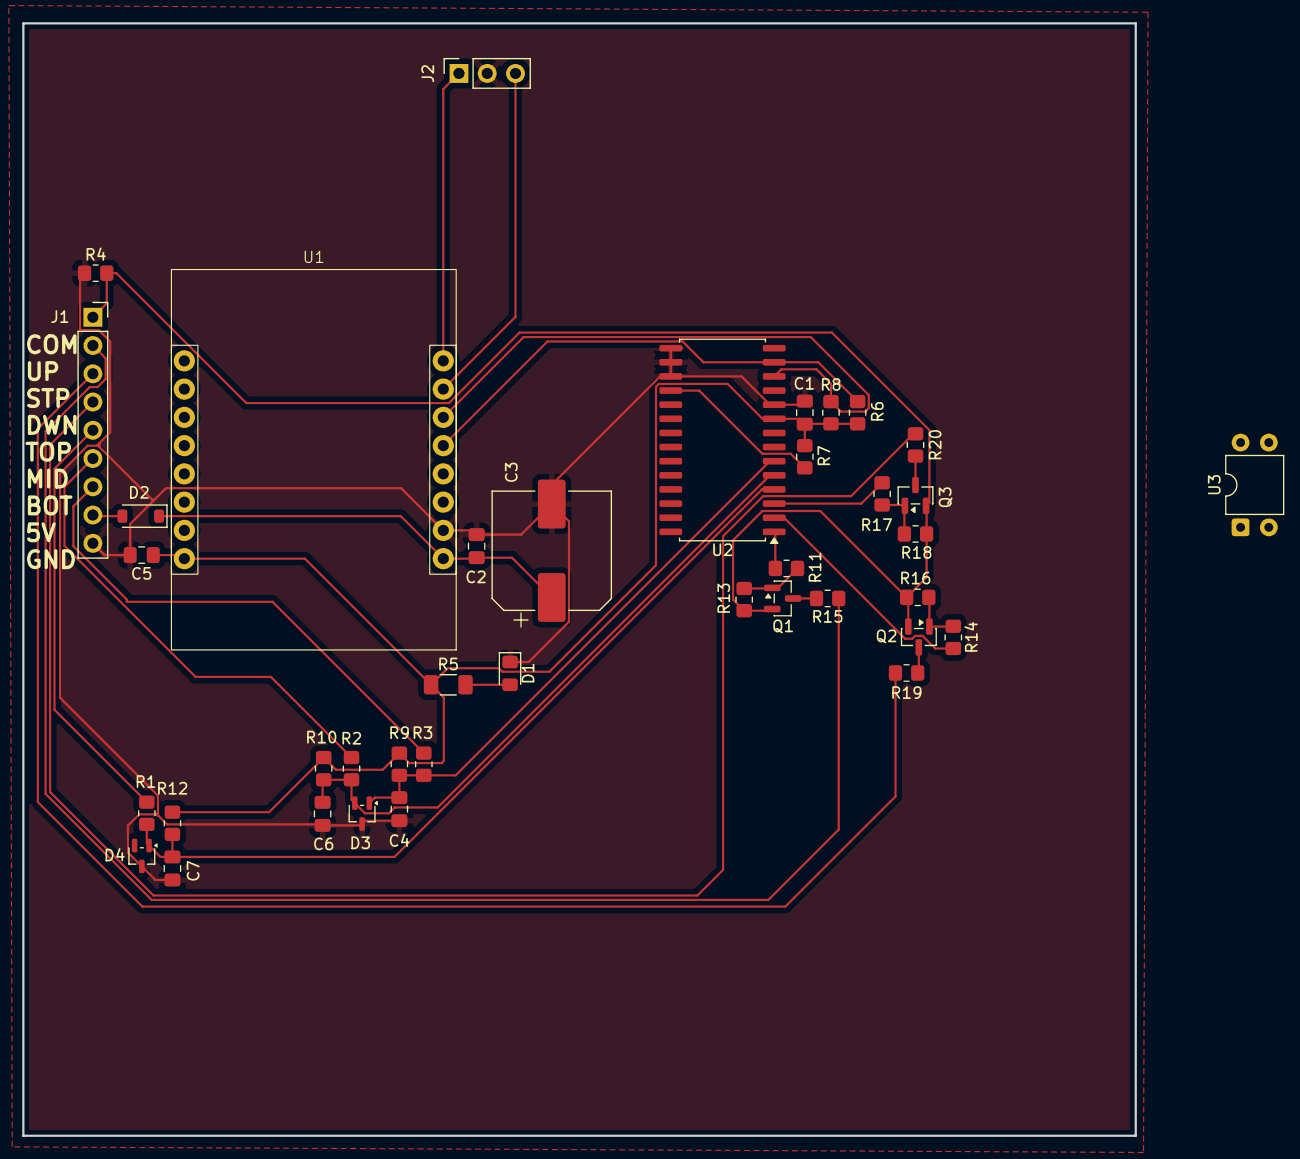
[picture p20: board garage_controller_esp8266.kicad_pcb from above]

Board: 2 copper layers, 100.0 x 100.0 mm, 39 parts (0 on the bottom side), 29 nets.

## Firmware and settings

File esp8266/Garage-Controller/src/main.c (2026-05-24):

#include "app.h"
#include "esp_common.h"
#include "freertos/FreeRTOS.h"
#include "freertos/task.h"
#include "log.h"

#include <string.h>
#include <stdio.h>


/******** RF CAL (required) ********/
void ICACHE_FLASH_ATTR user_rf_pre_init(void)
{
    /* Critical: Force full RF calibration on every boot for stability.
       This is especially important for cheap ESP8266 modules with poor RF. */
    /* Use supported API to request RF calibration behavior after power-up */
    system_phy_set_rfoption(1);
    /* Additional: Set max RF TX power (82 = 20.5dBm) for better range */
    system_phy_set_max_tpw(82);
}

uint32 ICACHE_FLASH_ATTR user_rf_cal_sector_set(void)
{
    flash_size_map size_map = system_get_flash_size_map();
    uint32 rf_cal_sec = 0;

    switch(size_map) {
        case FLASH_SIZE_4M_MAP_256_256:        rf_cal_sec = 128 - 5; break;
        case FLASH_SIZE_8M_MAP_512_512:        rf_cal_sec = 256 - 5; break;
        case FLASH_SIZE_16M_MAP_512_512:
        case FLASH_SIZE_16M_MAP_1024_1024:     rf_cal_sec = 512 - 5; break;
        case FLASH_SIZE_32M_MAP_512_512:
        case FLASH_SIZE_32M_MAP_1024_1024:     rf_cal_sec = 1024 - 5; break;
        case FLASH_SIZE_64M_MAP_1024_1024:     rf_cal_sec = 2048 - 5; break;
        case FLASH_SIZE_128M_MAP_1024_1024:    rf_cal_sec = 4096 - 5; break;
        default: rf_cal_sec = 0; break;
    }
    return rf_cal_sec;
}

/******** Entrypoint ********/
void user_init(void)
{
    
    uart_div_modify(0, UART_CLK_FREQ / 9600);
    LOGF("Booting...\n");
    flash_size_map sm = system_get_flash_size_map();
    uint32 rfsec = user_rf_cal_sector_set();
    LOGF("Flash map=%d, rf_cal_sector=%u\n", (int)sm, (unsigned)rfsec);
    struct rst_info *ri = system_get_rst_info();
    if (ri) {
        LOGF("Reset reason: %d, exccause=%d, epc1=0x%08x\n",
                ri->reason, ri->exccause, ri->epc1);
    }
    
    app_start();
}

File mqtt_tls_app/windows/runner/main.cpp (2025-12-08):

#include <flutter/dart_project.h>
#include <flutter/flutter_view_controller.h>
#include <windows.h>

#include "flutter_window.h"
#include "utils.h"

int APIENTRY wWinMain(_In_ HINSTANCE instance, _In_opt_ HINSTANCE prev,
                      _In_ wchar_t *command_line, _In_ int show_command) {
  // Attach to console when present (e.g., 'flutter run') or create a
  // new console when running with a debugger.
  if (!::AttachConsole(ATTACH_PARENT_PROCESS) && ::IsDebuggerPresent()) {
    CreateAndAttachConsole();
  }

  // Initialize COM, so that it is available for use in the library and/or
  // plugins.
  ::CoInitializeEx(nullptr, COINIT_APARTMENTTHREADED);

  flutter::DartProject project(L"data");

  std::vector<std::string> command_line_arguments =
      GetCommandLineArguments();

  project.set_dart_entrypoint_arguments(std::move(command_line_arguments));

  FlutterWindow window(project);
  Win32Window::Point origin(10, 10);
  Win32Window::Size size(1280, 720);
  if (!window.Create(L"mqtt_tls_app", origin, size)) {
    return EXIT_FAILURE;
  }
  window.SetQuitOnClose(true);

  ::MSG msg;
  while (::GetMessage(&msg, nullptr, 0, 0)) {
    ::TranslateMessage(&msg);
    ::DispatchMessage(&msg);
  }

  ::CoUninitialize();
  return EXIT_SUCCESS;
}

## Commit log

2026-01-04 Imrpoved wifi connection reliability and disabled the pull up for the button pins
2026-01-31 added kicad stuff
    [garage_controller_esp8266-B_Cu.gbr, garage_controller_esp8266-B_Mask.gbr, garage_controller_esp8266-B_Paste.gbr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]
2026-02-07 Started with box design
    [Assembly_GaragenBox.iam, Box.0001.ipt, BoxPrintTryout.stl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]
2026-03-14 Worked on the Box
    [Box_with_PCBRefernce.0001.ipt, Box_with_PCBRefernce.0002.ipt, Box_with_PCBRefernce.ipt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]
2026-03-20 Added uart
2026-03-22 Added interactive BOM
    [garage_controller_esp8266.csv]
2026-04-01 COntinued on box + clipper
    [Assembly_GaragenBox.0003.iam, Assembly_GaragenBox.iam, Box_derived.0002.ipt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]
2026-04-01 Improved spriung
    [Assembly_GaragenBox.0003.iam, Assembly_GaragenBox.0004.iam, Assembly_GaragenBox.iam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]
2026-05-09 Changed pins for buttons and added clipper
    [Assembly_GaragenBox.0005.iam, Assembly_GaragenBox.0009.iam, Assembly_GaragenBox.iam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]
2026-05-09 Improved clipper and added compartment for relay pcb
    [Bottom_part_improved.stp, Box_derived.0005.ipt, Box_derived.0006.ipt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]
2026-05-13 Improved top part
    [Top_part.0014.ipt, Top_part.0015.ipt, Top_part.ipt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]
2026-05-24 Changed uart speed

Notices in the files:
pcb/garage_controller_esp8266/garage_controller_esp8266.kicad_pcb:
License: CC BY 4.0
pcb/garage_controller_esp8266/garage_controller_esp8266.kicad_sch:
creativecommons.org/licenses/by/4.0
